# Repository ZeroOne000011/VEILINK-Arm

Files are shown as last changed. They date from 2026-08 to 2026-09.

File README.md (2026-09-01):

# VEILINK 六轴机械臂入门指南

VEILINK 是一款以 3D 打印结构件和飞特 STS3215 总线舵机为基础的六轴机械臂。本仓库整理了制作和调试这款机械臂所需的 3D 模型、装配说明、运动学参数及快速入门程序。

## 关于这个项目

我正在学习机械臂相关知识，VEILINK 是我设计的第一款机械臂，因此在设计和制作过程中，可能仍有一些不够完善的地方。希望这个项目能为同样对机械臂、机器人控制和 3D 打印感兴趣的朋友提供一些灵感，也欢迎大家一起学习、交流和探讨。

项目展示及打印配置可参考：[MakerWorld：VEILINK 六轴机械臂](https://makerworld.com.cn/zh/models/2817152-veilink-liu-zhou-ji-jie-bi#profileId-3285755)。

<p align="center">
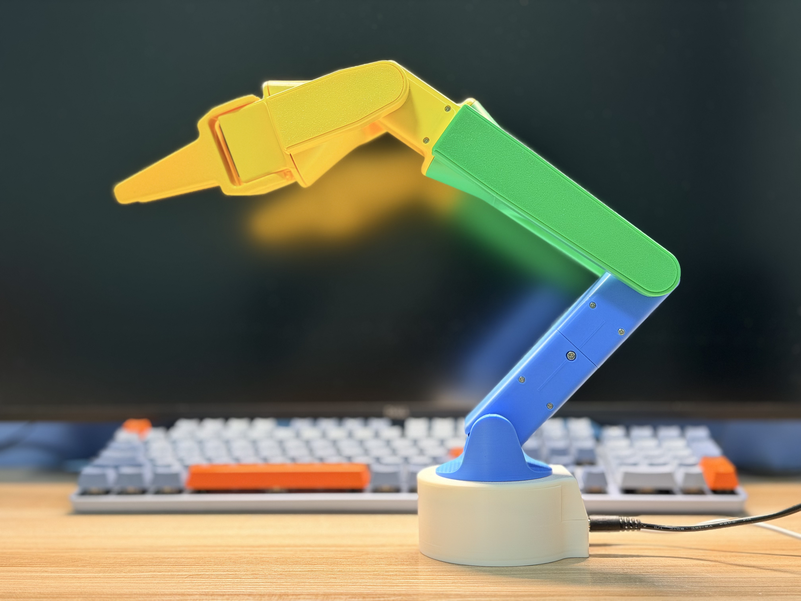
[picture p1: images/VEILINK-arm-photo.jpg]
VEILINK 六轴机械臂实拍图
  
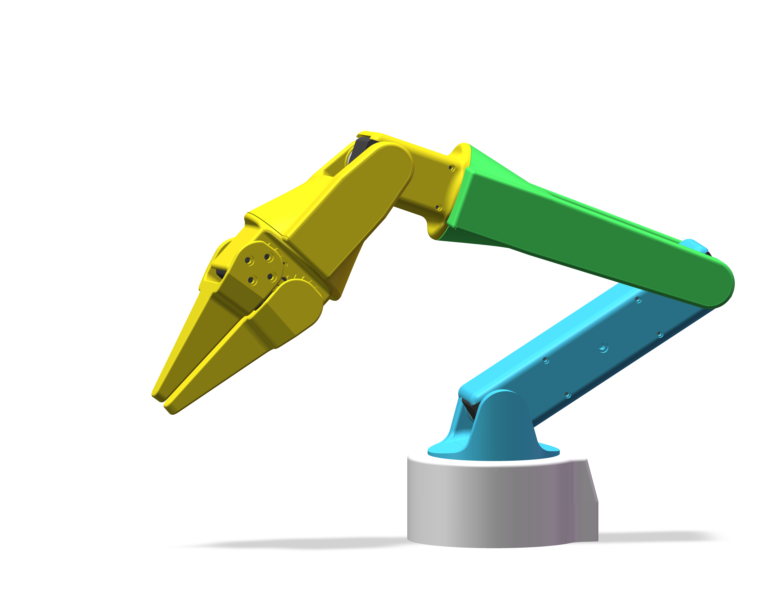
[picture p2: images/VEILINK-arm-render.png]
VEILINK 六轴机械臂 CAD 渲染图
  
</p>

## 仓库内容

| 目录 | 内容 |
| --- | --- |
| [3D Models](<3D Models/>) | 3MF 打印文件、STEP 三维模型和装配说明书 |
| [Code](<Code/>) | 舵机编号、整机校准、单舵机控制和 Xbox 手柄控制 Notebook |
| [运动学参数 Kinematic Parameters](<运动学参数 Kinematic Parameters/>) | 运动学参数说明、DH 参数表、运动学模型和零位示意图 |

主要资料：

- [3D 打印文件](<3D Models/VEILINK Arm 3D Print.3mf>)
- [STEP 三维模型](<3D Models/VEILINK Arm.STEP>)
- [装配说明书](<3D Models/装配说明书 Assembly Instruction.pdf>)
- [DH 参数表](<运动学参数 Kinematic Parameters/DH参数表 DH Parameters.png>)
- [运动学模型](<运动学参数 Kinematic Parameters/运动学模型 Kinematic Model.png>)
- [机械臂零位示意图](<运动学参数 Kinematic Parameters/零位 Zero Pose.PNG>)
- [运动学参数说明](<运动学参数 Kinematic Parameters/运动学参数说明.md>)

## 软件环境

快速入门 Notebook 按 LeRobot 0.5.x API 编写，当前校准记录使用 LeRobot 0.5.1。推荐使用 Anaconda 创建独立的 Python 环境，便于安装依赖、切换环境及避免不同项目之间的版本冲突。

### 1. 安装 Anaconda

前往 [Anaconda 官网](https://www.anaconda.com/download)下载并安装适合当前操作系统的版本。Windows 用户安装完成后，可从开始菜单打开 **Anaconda Prompt** 执行下面的命令。

先确认 Conda 已正确安装：

```powershell
conda --version
```

如果普通 PowerShell 提示找不到 `conda`，可改用 Anaconda Prompt，或在安装完成后重新打开终端。

### 2. 创建并激活项目环境

创建名为 `lerobot`、使用 Python 3.10 的独立环境：

```powershell
conda create -n lerobot python=3.10 -y
conda activate lerobot
```

激活成功后，终端提示符前通常会显示 `(lerobot)`。可以运行以下命令确认当前 Python 来自新环境：

```powershell
python --version
where.exe python
```

### 3. 安装项目依赖

在 `lerobot` 环境中执行：

```powershell
python -m pip install --upgrade pip
python -m pip install "lerobot==0.5.1" pyserial ipykernel ipywidgets jupyter numpy pygame
```

随后将该环境注册为 Jupyter 内核：

```powershell
python -m ipykernel install --user --name lerobot --display-name "Python (lerobot)"
```

### 4. 打开 Notebook

使用 VS Code 或 Jupyter 打开仓库中的 Notebook，并在右上角选择 `Python (lerobot)` 内核。串口号、夹爪选项及其他需要修改的参数，均在对应 Notebook 中标有说明。

以后再次使用时，只需打开 Anaconda Prompt 并激活环境：

```powershell
conda activate lerobot
```

常用的环境管理命令：

```powershell
conda env list                  # 查看已有环境
conda deactivate                # 退出当前环境
conda remove -n lerobot --all   # 删除 lerobot 环境
```

更多用法可参考 [Conda 环境管理文档](https://docs.conda.io/projects/conda/en/latest/user-guide/tasks/manage-environments.html)。

## 推荐使用顺序

### 1. 准备打印件和硬件

使用仓库中的 [3MF 文件](<3D Models/VEILINK Arm 3D Print.3mf>)打印结构件，并根据[装配说明书](<3D Models/装配说明书 Assembly Instruction.pdf>)准备舵机、控制板、电源、紧固件及工具。

### 2. 设置舵机编号

在机械装配前，打开 [1-舵机编号标记.ipynb](<Code/1-舵机编号标记.ipynb>)，按照其中的说明逐台设置舵机 ID、进行通信验证并粘贴实体标签。

### 3. 完成机械装配

按照[装配说明书](<3D Models/装配说明书 Assembly Instruction.pdf>)给出的方向和顺序安装舵机、舵盘、打印件及控制板。装配前后都应核对舵机标签与关节位置。

### 4. 校准零位和安全限位

机械装配完成后，参考[零位示意图](<运动学参数 Kinematic Parameters/零位 Zero Pose.PNG>)，运行 [2-舵机校准.ipynb](<Code/2-舵机校准.ipynb>)，记录各关节零位并采集安全限位。

校准结果会保存到 [机械臂校准参数.json](<Code/机械臂校准参数.json>)。仓库中的参数来自一台实际机械臂，仅用于展示数据结构和提供参考；不同设备的安装误差和安全范围并不相同，请务必为自己的机械臂重新校准。

### 5. 进行单关节调试

校准完成后，运行 [3-单舵机控制.ipynb](<Code/3-单舵机控制.ipynb>)，按照 Notebook 中的安全步骤逐个检查关节的位置反馈、运动方向、零位和限位，再逐步开展后续控制实验。

### 6. 使用 Xbox 手柄控制

完成校准和逐关节验证后，可以运行 [手柄操控机械臂.ipynb](<Code/手柄操控机械臂.ipynb>)，使用 Xbox 手柄控制腕部中心移动、腕部关节、末端旋转和夹爪开合。该 Notebook 使用 Pygame 的 SDL 标准手柄映射，并从同一份校准 JSON 读取 DH 参数、零位和软件限位。

首次使用时，请先完成 Notebook 中的手柄输入预览和离线回归测试，再以最低速度档进行短脉冲实机验证。控制过程中，短按 A 可在控制与保持状态之间切换，长按 A 退出循环并保持位置，B 键用于锁存紧急卸力；软件卸力不能替代实体断电或急停措施。

### 7. 使用运动学资料

需要进行正逆运动学、轨迹规划或上层控制开发时，建议先阅读[运动学参数说明](<运动学参数 Kinematic Parameters/运动学参数说明.md>)，再结合 [DH 参数表](<运动学参数 Kinematic Parameters/DH参数表 DH Parameters.png>)、[运动学模型](<运动学参数 Kinematic Parameters/运动学模型 Kinematic Model.png>)和零位示意图进行验证。

## 安全提示

- 开始装配或调试前，请完整阅读装配说明书和对应 Notebook 中的安全要求。
- 通电前核对舵机额定电压、接线极性、外部电源容量及控制板与电源共地情况。
- 调试承重关节时应可靠固定机械臂并托住连杆，避免卸力后突然下坠。
- 首次运动测试应采用低速、小幅度、逐关节的方式进行。
- 出现异常运动、发热、异味、异响、通信错误或结构干涉时，应立即卸力并切断舵机电源。

```text
准备打印件和硬件
        ↓
设置舵机 ID 并粘贴标签
        ↓
完成机械装配与接线
        ↓
校准零位和安全限位
        ↓
逐关节进行低速、小幅度测试
        ↓
验证 Xbox 手柄输入与安全停止逻辑
        ↓
开展运动学与上层控制开发
```

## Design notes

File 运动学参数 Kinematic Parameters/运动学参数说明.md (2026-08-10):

# VEILINK 六轴机械臂运动学参数说明

本文面向第一次接触机械臂运动学的读者，说明 VEILINK 六轴机械臂的零位、关节方向、标准 DH 参数以及如何用这些参数计算工具中心点（TCP）的位置和姿态。

> 本文中的长度单位均为 **mm**，角度单位均为 **°**。编程计算三角函数前，必须把角度转换为弧度。

## 1. 先认识这台机械臂

VEILINK 机械臂由 6 个旋转关节组成：

- **J1～J3** 主要决定手腕中心在空间中的位置；
- **J4～J6** 主要调整末端执行器的姿态；
- 夹爪开合是独立动作，不计入机械臂的 6 个位姿自由度，也不在本 DH 参数表中。

机械臂的完整“位姿”包含两部分：

- **位置**：TCP 在基座坐标系中的 `x、y、z` 坐标；
- **姿态**：末端坐标系相对于基座坐标系的朝向。

因此，六轴机械臂通常可以同时控制 TCP 的 3 个位置自由度和 3 个姿态自由度。

### 1.1 参考图

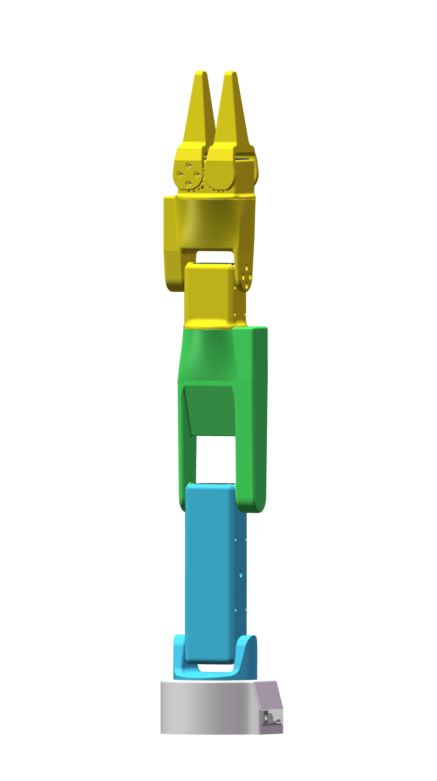
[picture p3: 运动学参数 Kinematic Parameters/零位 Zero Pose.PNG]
VEILINK 机械臂零位实物示意


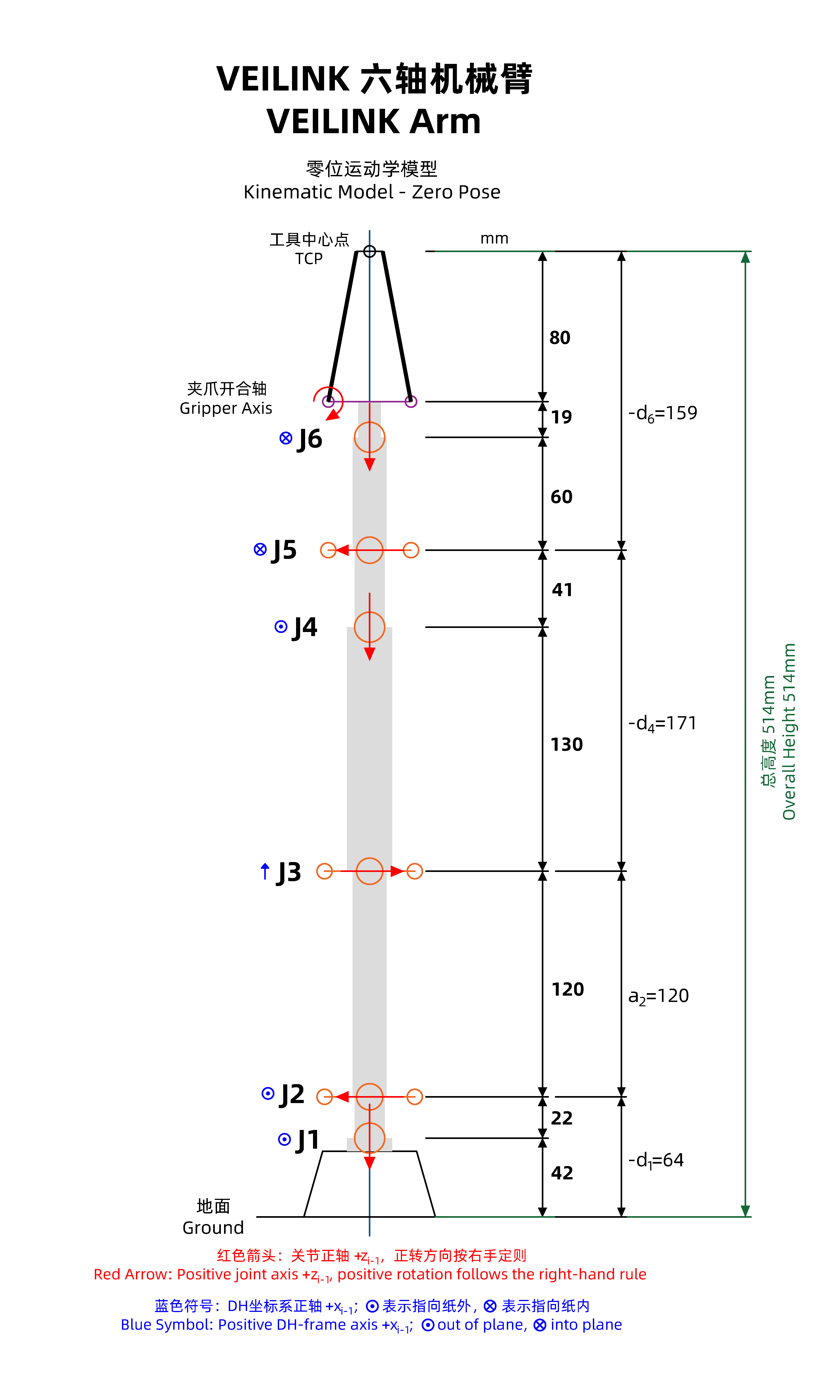
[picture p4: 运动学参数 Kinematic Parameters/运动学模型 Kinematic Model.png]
VEILINK 机械臂零位运动学模型


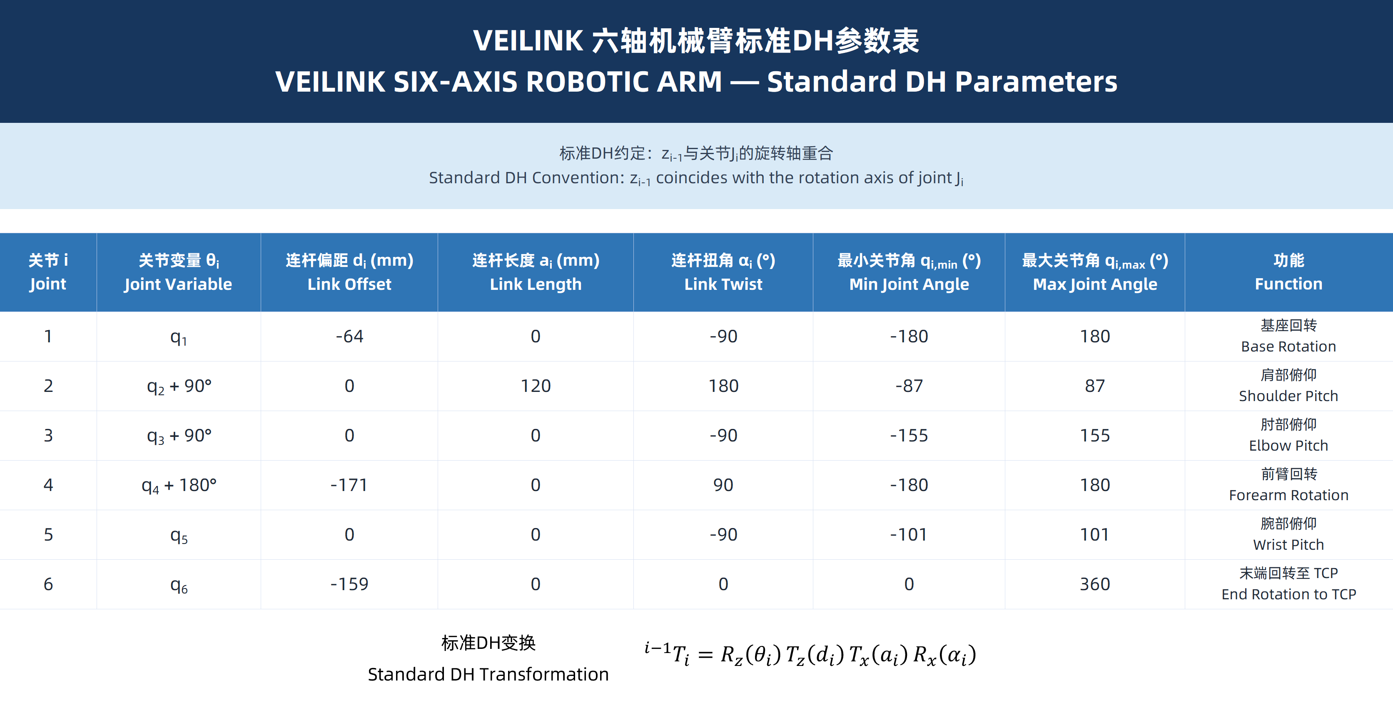
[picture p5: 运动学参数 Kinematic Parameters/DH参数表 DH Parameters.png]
VEILINK 六轴机械臂标准 DH 参数表


## 2. 零位、TCP 与坐标方向

### 2.1 什么是机械零位

本文把下列状态定义为机械臂零位：

```text
q = [q1, q2, q3, q4, q5, q6] = [0°, 0°, 0°, 0°, 0°, 0°]
```

此时机械臂外形如零位图所示，主体连杆大致竖直向上。零位是描述所有关节角的共同参考，不代表舵机原始编码值一定为 0。实际控制时，必须通过校准把舵机编码值换算为本文中的关节角 `qi`。

### 2.2 什么是 TCP

**TCP（Tool Center Point，工具中心点）** 是控制末端工具时使用的参考点。本文模型把 TCP 放在夹爪顶部中心线上。若以后更换夹爪、吸盘或其他工具，应重新测量工具长度，并在第 6 关节之后增加相应的工具变换。

在图示零位中：

- 地面到 TCP 的总高度为 **514 mm**；
- TCP 位于机械臂中心线上；
- 夹爪开合轴位于 TCP 下方 **80 mm**。

### 2.3 图中的箭头和圆点符号

- **红色箭头**：关节正轴 `+z(i-1)`；关节正转遵循右手定则；
- **蓝色符号**：对应 DH 坐标系的正 `+x(i-1)` 方向；
- `⊙`：方向垂直纸面向外；
- `⊗`：方向垂直纸面向内。

右手定则可以这样理解：右手拇指指向关节正轴，其余四指弯曲的方向就是关节角增大的方向。

> 不能只根据屏幕上“顺时针/逆时针”判断正负方向。观察视角改变后，视觉上的旋转方向也会改变；关节正方向应始终由轴向和右手定则确定。

### 2.4 零位图中的主要尺寸

从地面沿竖直方向到 TCP，各段尺寸依次为：

| 区段 | 尺寸（mm） | 说明 |
| --- | ---: | --- |
| 地面到 J1 轴 | 42 | 基座高度的一部分 |
| J1 轴到 J2 轴 | 22 | 与上一段合计得到 `-d1 = 64` |
| J2 轴到 J3 轴 | 120 | 对应 `a2 = 120` |
| J3 轴到 J4 轴 | 130 | 前臂下段尺寸 |
| J4 轴到 J5 轴 | 41 | 与上一段合计得到 `-d4 = 171` |
| J5 轴到 J6 附近参考面 | 60 | 腕部/末端结构尺寸的一部分 |
| 参考面到夹爪开合轴 | 19 | 与相邻尺寸共同构成末端偏距 |
| 夹爪开合轴到 TCP | 80 | 夹爪工具长度 |
| **合计** | **514** | 零位总高度 |

这里出现负的 `d1、d4、d6`，不是长度为负，而是因为相应位移方向与所定义坐标轴正方向相反。

## 3. 标准 DH 参数是什么

DH（Denavit–Hartenberg）方法用 4 个参数描述相邻两节连杆坐标系之间的关系。本文采用的是 **标准 DH（Standard DH）**，约定：

> `z(i-1)` 轴与关节 `Ji` 的旋转轴重合。

每一行 DH 参数包含：

| 参数 | 中文名称 | 对旋转关节的含义 |
| --- | --- | --- |
| `θi` | 关节角 | 绕 `z(i-1)` 旋转的角度；本机械臂的变量项来自 `qi` |
| `di` | 连杆偏距 | 沿 `z(i-1)` 平移的距离 |
| `ai` | 连杆长度 | 沿 `xi` 平移的距离 |
| `αi` | 连杆扭角 | 绕 `xi` 旋转，使 `z(i-1)` 转向 `zi` 的角度 |

对于第 `i` 个关节，从坐标系 `{i-1}` 到 `{i}` 的标准 DH 变换为：

```text
^(i-1)Ti = Rz(θi) · Tz(di) · Tx(ai) · Rx(αi)
```

展开成齐次变换矩阵：

```text
             ┌ cosθ  -sinθ·cosα   sinθ·sinα   a·cosθ ┐
^(i-1)Ti  =  │ sinθ   cosθ·cosα  -cosθ·sinα   a·sinθ │
             │   0       sinα         cosα        d   │
             └   0         0            0         1   ┘
```

矩阵左上角 `3×3` 部分表示姿态，最右侧前三个数表示位置。

> “标准 DH”和“改进 DH（Modified DH）”的坐标系附着方式及变换顺序不同。本文参数不能直接代入改进 DH 公式。

## 4. 本机械臂的 DH 参数

| 关节 | DH 关节变量 `θi` | `di`（mm） | `ai`（mm） | `αi` | `qi` 最小值 | `qi` 最大值 | 主要功能 |
| ---: | --- | ---: | ---: | ---: | ---: | ---: | --- |
| J1 | `q1` | -64 | 0 | -90° | -180° | 180° | 基座回转 |
| J2 | `q2 + 90°` | 0 | 120 | 180° | -87° | 87° | 肩部俯仰 |
| J3 | `q3 + 90°` | 0 | 0 | -90° | -155° | 155° | 肘部俯仰 |
| J4 | `q4 + 180°` | -171 | 0 | 90° | -180° | 180° | 前臂回转 |
| J5 | `q5` | 0 | 0 | -90° | -101° | 101° | 腕部俯仰 |
| J6 | `q6` | -159 | 0 | 0° | 0° | 360° | 末端回转至 TCP |

### 4.1 `qi` 与 `θi` 不完全相同

`qi` 是以机械零位为 0° 的实际关节变量，`θi` 是代入 DH 变换矩阵的角度。两者关系为：

```text
θ1 = q1
θ2 = q2 + 90°
θ3 = q3 + 90°
θ4 = q4 + 180°
θ5 = q5
θ6 = q6
```

`+90°` 或 `+180°` 是由 DH 坐标系定义产生的固定补偿，并不表示机械臂回到零位时还要命令舵机额外旋转这些角度。

### 4.2 为什么只有 `a2` 不为 0

`ai` 表示两根相邻关节轴之间沿公共法线的距离。这个模型中，J2 与 J3 之间存在 **120 mm** 的公共法线距离，因此 `a2=120 mm`；其余相邻轴在各自 DH 建系下相交或共线，所以相应 `ai=0`。

### 4.3 `d4` 和 `d6` 包含哪些实体尺寸

- `-d4=171 mm`，对应图中 `130+41 mm`；
- `-d6=159 mm`，对应图中 `60+19+80 mm`，其终点为 TCP；
- `-d1=64 mm`，对应图中 `42+22 mm`。

这些是用于坐标变换的等效几何尺寸，不要求每个 DH 参数只对应一根独立的实体连杆。

## 5. 六个关节逐一说明

### 5.1 J1：基座回转（Base Rotation）

- **作用**：带动 J2～J6 和末端工具绕基座轴整体旋转，主要改变 TCP 的水平朝向；
- **关节变量**：`θ1=q1`；
- **范围**：`-180° ≤ q1 ≤ 180°`；
- **零位轴向**：正轴沿图中的红色 `+z0`；
- **直观理解**：类似人站在原地转身；
- **注意**：当 TCP 位于基座轴线上时，仅从 TCP 位置可能无法唯一确定 J1，姿态或前一时刻关节角也要参与选解。

### 5.2 J2：肩部俯仰（Shoulder Pitch）

- **作用**：抬起或放下整条手臂，对 TCP 的伸出距离和高度影响很大；
- **关节变量**：`θ2=q2+90°`；
- **范围**：`-87° ≤ q2 ≤ 87°`；
- **几何参数**：`a2=120 mm`；
- **直观理解**：类似人的肩膀带动上臂前后摆动；
- **注意**：接近上下限时应预留减速和机械安全余量，不应把表中理论边界直接当作高速运动边界。

### 5.3 J3：肘部俯仰（Elbow Pitch）

- **作用**：改变手臂弯曲程度，与 J2 配合决定“肘上/肘下”等不同构型；
- **关节变量**：`θ3=q3+90°`；
- **范围**：`-155° ≤ q3 ≤ 155°`；
- **直观理解**：类似人的肘关节屈伸；
- **注意**：同一个 TCP 目标可能有多组 J2/J3 解，逆运动学时要根据限位、避障和与当前姿态的距离选解。

### 5.4 J4：前臂回转（Forearm Rotation）

- **作用**：使腕部绕前臂方向滚转，主要改变末端姿态；
- **关节变量**：`θ4=q4+180°`；
- **范围**：`-180° ≤ q4 ≤ 180°`；
- **几何参数**：`d4=-171 mm`；
- **直观理解**：类似人的前臂旋前/旋后；
- **注意**：固定补偿 `+180°` 只在运动学计算中加入，不能重复加入舵机命令。

### 5.5 J5：腕部俯仰（Wrist Pitch）

- **作用**：使末端工具抬头或低头，是调整夹爪朝向的关键关节；
- **关节变量**：`θ5=q5`；
- **范围**：`-101° ≤ q5 ≤ 101°`；
- **直观理解**：类似手腕上下弯曲；
- **注意**：在 `q5` 接近某些轴线重合构型（特别是零附近）时，J4 与 J6 对姿态的作用可能耦合，属于腕部奇异附近，应避免用很大的关节速度追踪微小姿态变化。

### 5.6 J6：末端回转（End Rotation）

- **作用**：使夹爪绕末端中心轴旋转；
- **关节变量**：`θ6=q6`；
- **范围**：`0° ≤ q6 ≤ 360°`；
- **几何参数**：`d6=-159 mm`，从腕部坐标系延伸到 TCP；
- **直观理解**：类似拧动螺丝刀；
- **注意**：0° 与 360° 的几何姿态相同，但控制器数值可能不同。轨迹规划应采用连续角度或最短角差，避免在边界处突然反转一整圈。

### 5.7 夹爪开合轴（Gripper Axis）

夹爪开合只改变两指间距，不改变本文定义的 TCP 坐标系，因此没有单独的 DH 行。若抓取物体后希望把抓取点而不是夹爪顶部中心作为 TCP，应增加一个工具坐标系，并写出从当前 TCP 到新工具点的固定变换。

## 6. 如何计算正运动学

正运动学解决的问题是：**已知六个关节角，求 TCP 的位置和姿态。**

计算步骤：

1. 输入机械零位定义下的 `q1～q6`；
2. 检查每个 `qi` 是否在关节范围内；
3. 按上文关系计算 `θ1～θ6`；
4. 将每行的 `θi、di、ai、αi` 代入标准 DH 矩阵，得到 `^(i-1)Ti`；
5. 按关节顺序左乘：

```text
^0T6 = ^0T1 · ^1T2 · ^2T3 · ^3T4 · ^4T5 · ^5T6
```

最终矩阵写作：

```text
       ┌ r11 r12 r13 px ┐
^0T6 = │ r21 r22 r23 py │
       │ r31 r32 r33 pz │
       └  0   0   0   1 │
```

- `p=[px,py,pz]ᵀ` 是 TCP 在基座坐标系中的位置；
- `R`（左上角 `3×3`）是 TCP 的姿态旋转矩阵。

### 6.1 可直接参考的 Python 实现

```python
import numpy as np

def dh_standard(theta_deg, d_mm, a_mm, alpha_deg):
    """返回标准 DH 齐次变换矩阵。"""
    theta = np.deg2rad(theta_deg)
    alpha = np.deg2rad(alpha_deg)
    ct, st = np.cos(theta), np.sin(theta)
    ca, sa = np.cos(alpha), np.sin(alpha)

    return np.array([
        [ct, -st * ca,  st * sa, a_mm * ct],
        [st,  ct * ca, -ct * sa, a_mm * st],
        [0.0,      sa,       ca,       d_mm],
        [0.0,     0.0,      0.0,        1.0],
    ])

def forward_kinematics(q_deg):
    """q_deg: [q1, q2, q3, q4, q5, q6]，单位为度。"""
    q = np.asarray(q_deg, dtype=float)
    if q.shape != (6,):
        raise ValueError("q_deg 必须包含 6 个关节角")

    q_min = np.array([-180, -87, -155, -180, -101,   0], dtype=float)
    q_max = np.array([ 180,  87,  155,  180,  101, 360], dtype=float)
    if np.any(q < q_min) or np.any(q > q_max):
        raise ValueError("存在超出 DH 参数表范围的关节角")

    theta = q + np.array([0, 90, 90, 180, 0, 0], dtype=float)
    d = np.array([-64, 0, 0, -171, 0, -159], dtype=float)
    a = np.array([0, 120, 0, 0, 0, 0], dtype=float)
    alpha = np.array([-90, 180, -90, 90, -90, 0], dtype=float)

    T = np.eye(4)
    for values in zip(theta, d, a, alpha):
        T = T @ dh_standard(*values)
    return T

T_0_tcp = forward_kinematics([0, 0, 0, 0, 0, 0])
print(T_0_tcp)
print("TCP position (mm):", T_0_tcp[:3, 3])
```

### 6.2 用零位做自检

将 `q=[0,0,0,0,0,0]°` 代入本文参数，理论结果为：

```text
         ┌ -1  0  0    0 ┐
^0Ttcp = │  0 -1  0    0 │
         │  0  0  1 -514 │
         └  0  0  0    1 ┘
```

这表示：

- TCP 位于基座中心线上；
- 沿本模型定义的基座 `+z0` 反方向移动 514 mm；
- 物理上对应图中的“从地面竖直向上 514 mm”；
- TCP 坐标系的 x、y 轴相对基座各反向，z 轴同向。

如果零位计算结果不是这个位置，优先检查：是否误用了改进 DH、矩阵相乘顺序是否颠倒、是否遗漏固定角补偿，以及角度是否正确转换为弧度。

## 7. 逆运动学、限位与奇异位形

逆运动学解决的问题是：**已知期望 TCP 位姿，求六个关节角。** 它通常比正运动学更复杂，原因包括：

- 同一目标位姿可能有多组关节解；
- 某些目标超出机械臂工作空间，没有可行解；
- 数学上存在的解可能超过关节限位或发生结构干涉；
- 奇异位形附近，末端的小变化可能需要很大的关节运动。

常见选解原则：

1. 先剔除超过各关节范围的解；
2. 再剔除会造成连杆、夹爪、桌面或环境碰撞的解；
3. 优先选择与当前关节角距离较小的连续解；
4. 给机械限位和奇异位形留出安全余量；
5. 在真实机械臂上先低速、单步、小幅度验证。

需要特别留意的构型包括：手臂接近完全伸直或折叠，以及腕部轴线接近重合。此时机械臂仍可能处在正常几何位置，但某些方向的运动能力下降，数值逆解也可能变得不稳定。

## 8. 从运动学角度到真实舵机指令

DH 模型中的 `qi` 与舵机内部位置值之间通常还隔着一层标定关系：

```text
舵机编码值 → 零位偏置修正 → 方向符号修正 → 关节角 qi → DH 角 θi
```

实际使用时应分别保存：

- 每个关节的舵机编号；
- 机械零位对应的编码值；
- 编码增大是否等于本文关节正方向；
- 实机测得的安全软限位；
- 编码值与角度之间的比例关系。

> DH 参数表中的角度范围用于运动学建模和规划参考，不能替代具体机械臂的实机校准、碰撞检查和安全软限位。

## 9. 初学者常见问题

### 为什么 `d` 可以是负数？

`d` 是带方向的坐标位移，不是物体的“负长度”。负号只表示位移方向与相应 z 轴正方向相反。

### 为什么零位时 `θ2、θ3、θ4` 不是 0°？

因为 `θi` 是 DH 坐标系之间的角度，而 `qi` 是以机械零位为基准的关节角。固定的 90° 或 180° 用于把两套定义对齐。

### 为什么 J6 的范围写成 0°～360°？

它表达一整圈可用范围。0° 与 360° 姿态等价，但规划连续轨迹时仍要处理数值跨界问题，并核对线缆是否允许连续回转。

### 只控制 TCP 位置，是否一定要用六个关节？

不一定。前三个关节通常承担主要定位任务，后三个关节主要负责姿态，但各关节并非完全独立。完整的空间位姿控制仍需联合求解六个关节。

### 更换夹爪后要重新做整套 DH 参数吗？

如果 J1～J6 的结构没有变化，通常不必修改前六行 DH 参数，只需重新定义从 J6 到新 TCP 的工具变换；若第 6 轴到安装面的结构尺寸也改变，则应同步更新相应末端偏距。

## 10. 建议的学习与验证顺序

1. 对照零位实物图识别 J1～J6 和夹爪轴；
2. 用右手定则逐个确认关节正方向；
3. 理解 `qi`、`θi` 与固定角补偿的区别；
4. 用零位验证正运动学结果和 514 mm 总高度；
5. 给单个关节增加少量角度，观察 TCP 位置和姿态的变化；
6. 加入关节限位、连续角度处理和碰撞检查；
7. 最后再学习数值逆运动学、雅可比矩阵和轨迹规划。

完成以上步骤后，就具备了使用本组参数进行正运动学验证、逆运动学开发和上层轨迹规划的基础。

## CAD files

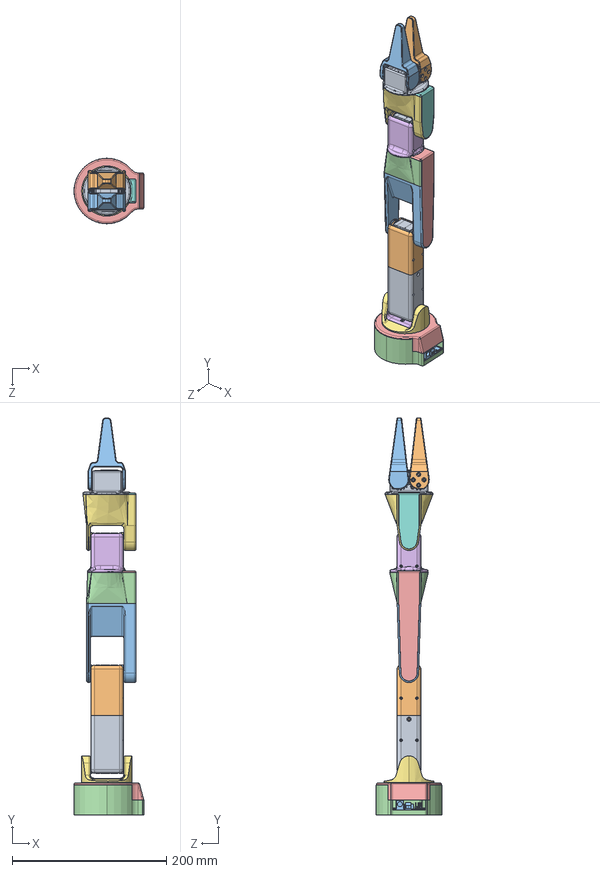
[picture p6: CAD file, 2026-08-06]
3D Models/VEILINK Arm.STEP
90.7 x 514.0 x 85.0 mm
ST3215电机 x 7
舵盘 x 7
驱动板
底座
底座盖
肩部旋转
肩部旋转盖
辅助舵盘 x 4
上臂
前臂
前臂腕部底座
前臂装饰盖
腕部俯仰底座
末端旋转底座
腕部装饰盖
夹爪固定底座
夹爪
辅助夹爪

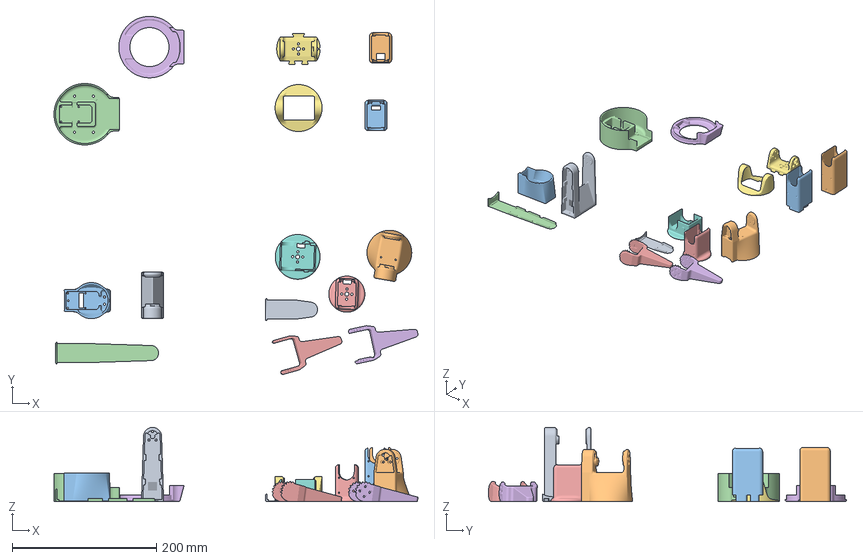
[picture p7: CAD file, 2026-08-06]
3D Models/VEILINK Arm 3D Print.3mf
503.9 x 495.9 x 102.6 mm
前臂.STEP
末端旋转底座.STEP
前臂腕部底座.STEP
前臂装饰盖.STEP
腕部俯仰底座.STEP
夹爪.STEP
肩部旋转盖.STEP
夹爪固定底座.STEP
腕部装饰盖.STEP
上臂_1
上臂_2
底座.STEP
辅助夹爪.STEP
底座盖.STEP
肩部旋转.STEP

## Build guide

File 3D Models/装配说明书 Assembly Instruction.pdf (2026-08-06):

# VEILINK 六轴机械臂

# VEILINK Six-Axis Robotic Arm

# 装配说明书

# Assembly Instruction

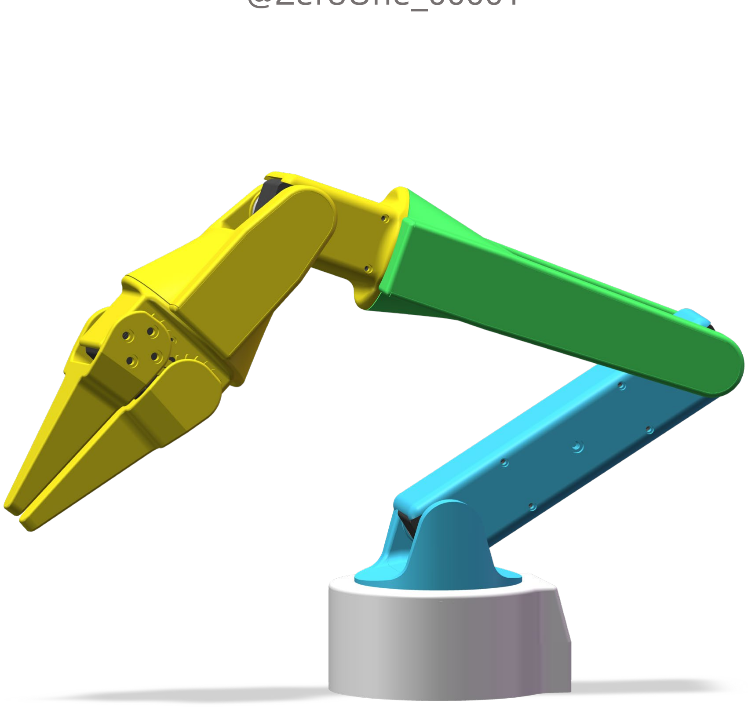
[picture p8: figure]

### @ZeroOne_00001

# 材料清单

## BOM

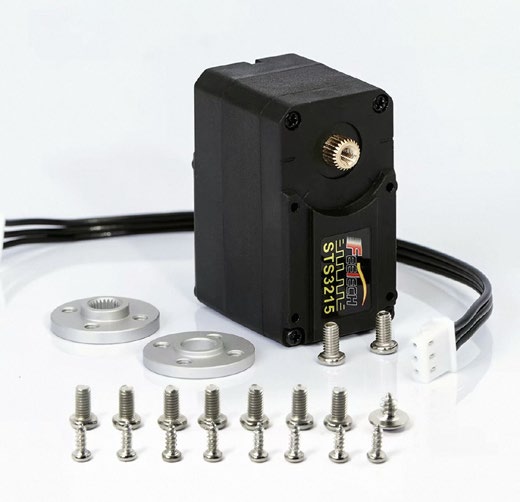
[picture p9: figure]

飞特舵机STS3215 C001 7.4V
FEETECH STS3215 C001 7.4V

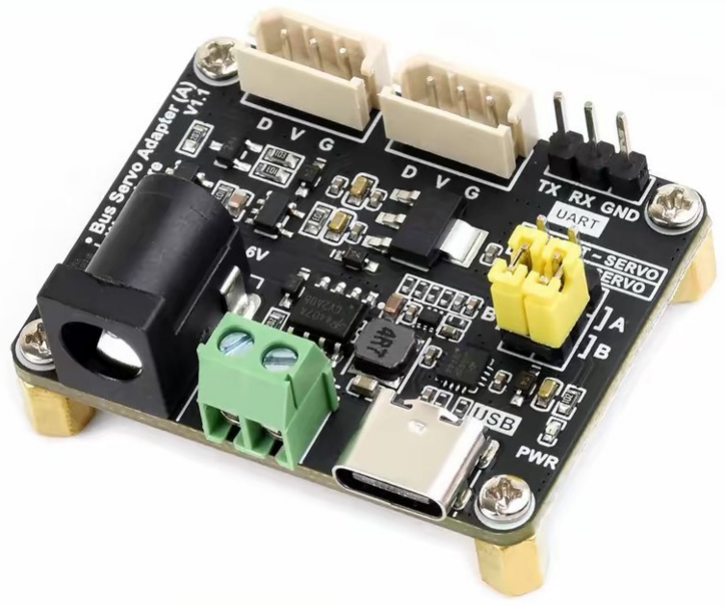
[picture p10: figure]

微雪总线舵机驱动板
WAVESHARE Bus Servo Adapter

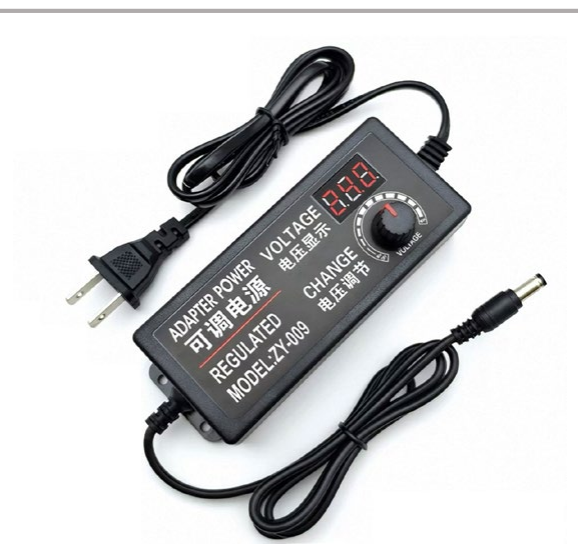
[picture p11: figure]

3-12V可调电源
3–12 V Adjustable Power Supply

3D打印件
3D-Printed Parts

Type-c USB数据线
USB Type-C Data Cable

https://e.tb.cn/h.8gToyH7nGQLqJIb?tk=YCCKgyzv9Hm (https://e.tb.cn/h.8gToyH7nGQLqJIb?tk=YCCKgyzv9Hm)

https://e.tb.cn/h.8gTOINQEOKyP67f?tk=t9xmgyzsh4T (https://e.tb.cn/h.8gTOINQEOKyP67f?tk=t9xmgyzsh4T)

https://e.tb.cn/h.8TIiKoLDCdxslsV?tk=bbOtgyAhpHh (https://e.tb.cn/h.8TIiKoLDCdxslsV?tk=bbOtgyAhpHh)

×7

×1

×1

×1

×15

# 装配前须知

### 欢迎制作 VEILINK 六轴机械臂！为确保装配过程顺利， 请在开始前阅读以下内容。

## 快速入门与代码

### 快速入门指南、运动学参数及相关资料：

https://github.com/ZeroOne000011/VEILINK-Arm

## 注意事项

### - 由于舵机外观相同，请务必在装配前完成舵机ID设 置，并在安装前再次核对每个舵机的编号和安装位 置。编号错误可能导致关节动作异常、运动方向不 正确，甚至造成机械结构碰撞。 - 建议按照说明书中的方向安装舵机和摆臂。 - 在打印件完全冷却后再拆除支撑，并清理毛边及孔 内残留材料。必要时可先试装螺丝，确认各连接位 置配合正常。预计装配时间约为20分钟。

## 建议准备的工具

### - 十字螺丝刀 - 尖嘴钳

- 剪钳

## Before Assembly

Welcome to the VEILINK Six-Axis Robotic Arm project! To ensure a smooth assembly process, please read the following information before getting started.

## Quick Start Guide and Code

Quick-start guide, kinematic parameters, and related opensource resources:
https://github.com/ZeroOne000011/VEILINK-Arm

## Important Notes

- Since all the servos look identical, make sure to configure their IDs before assembly. Before installation, doublecheck each servo ID and its corresponding mounting position. An incorrect ID may cause abnormal joint movement, an incorrect direction of rotation, or even collisions between mechanical parts.
- Install the servos and servo horns in the orientations shown in the assembly guide.
- Allow the printed parts to cool completely before removing the supports. Clean away any rough edges and residual material inside the holes. If necessary, test-fit the screws first to ensure that all parts fit together correctly.The estimated assembly time is approximately 20 minutes.

## Recommended Tools

- Phillips screwdriver
- Needle-nose pliers
- Flush cutters

1

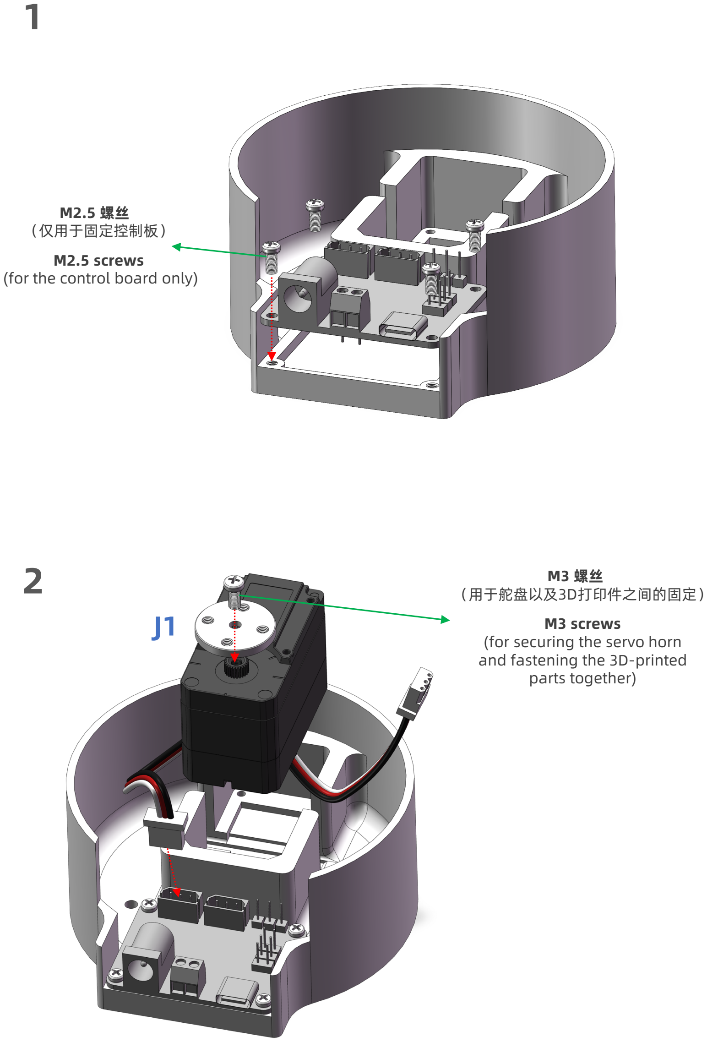
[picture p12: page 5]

2

M2.5 螺丝
（仅用于固定控制板）
M2.5 screws
(for the control board only)

M3 螺丝
（用于舵盘以及3D打印件之间的固定）
M3 screws
(for securing the servo horn and fastening the 3D-printed parts together)

J1

3

4

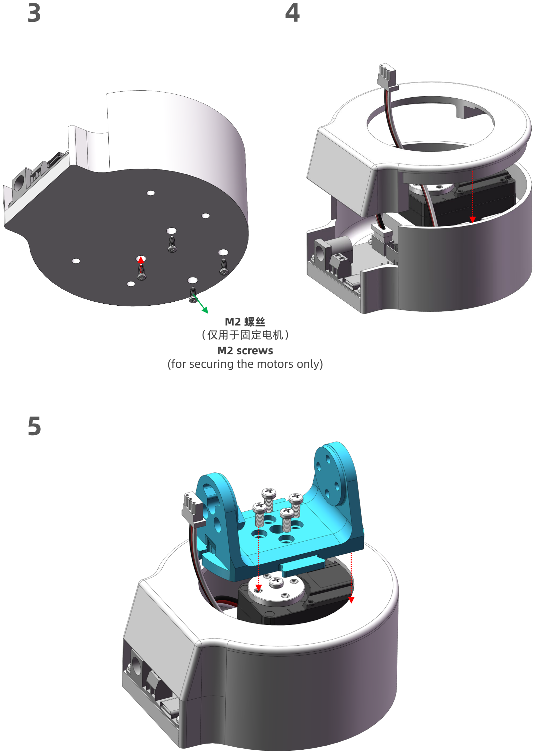
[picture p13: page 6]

5

M2 螺丝
（仅用于固定电机）
M2 screws
(for securing the motors only)

6

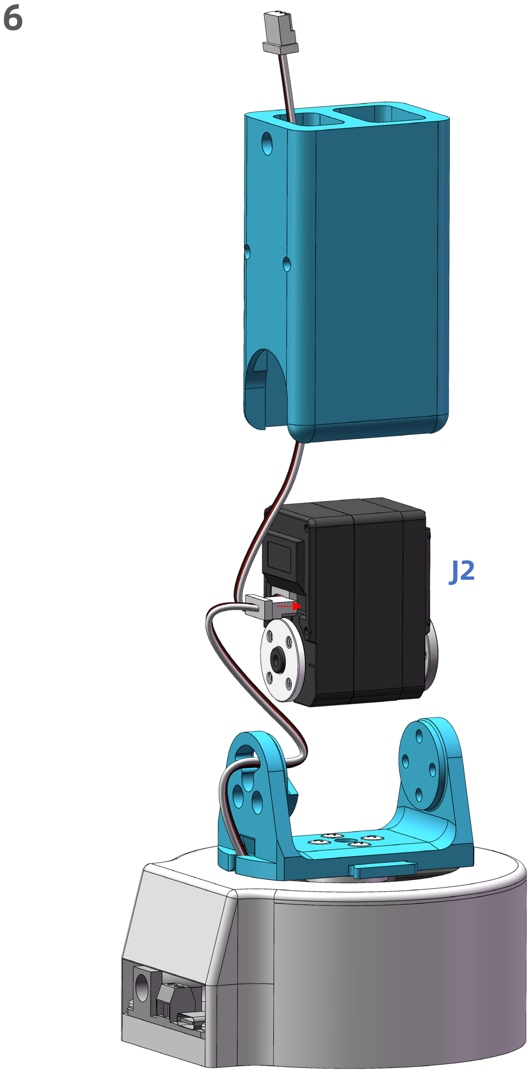
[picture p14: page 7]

J2

7

8

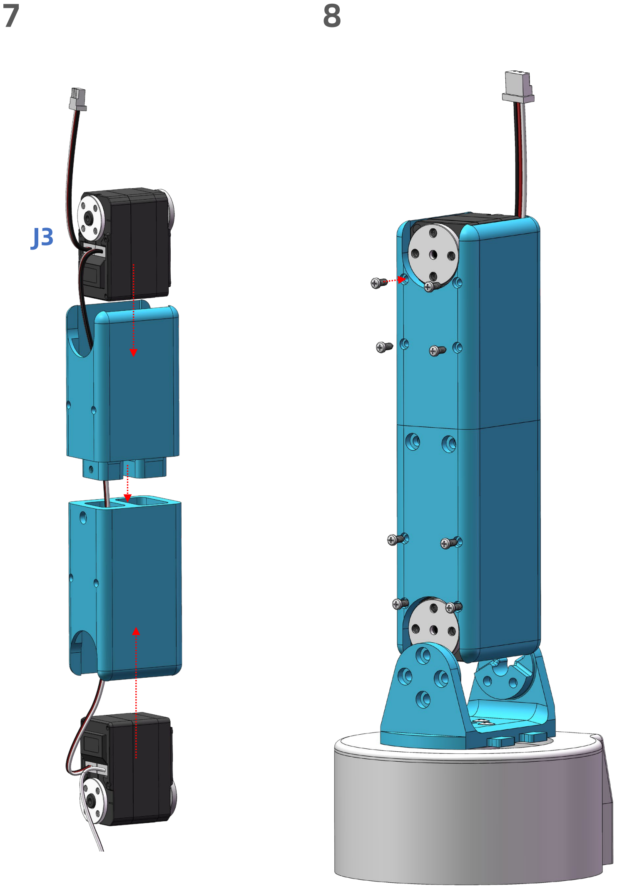
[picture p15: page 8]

J3

9 10

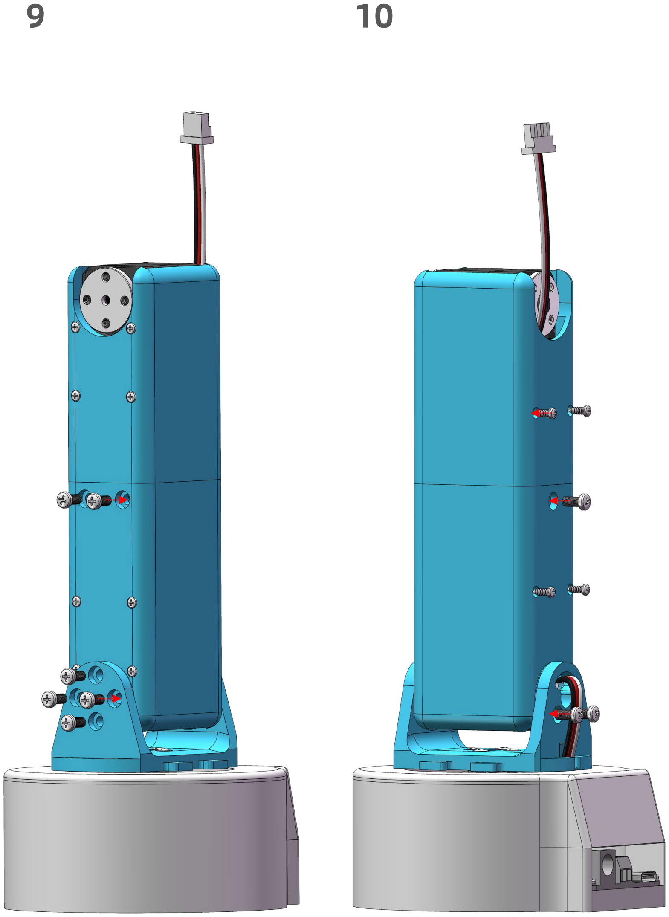
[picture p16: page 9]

11 12

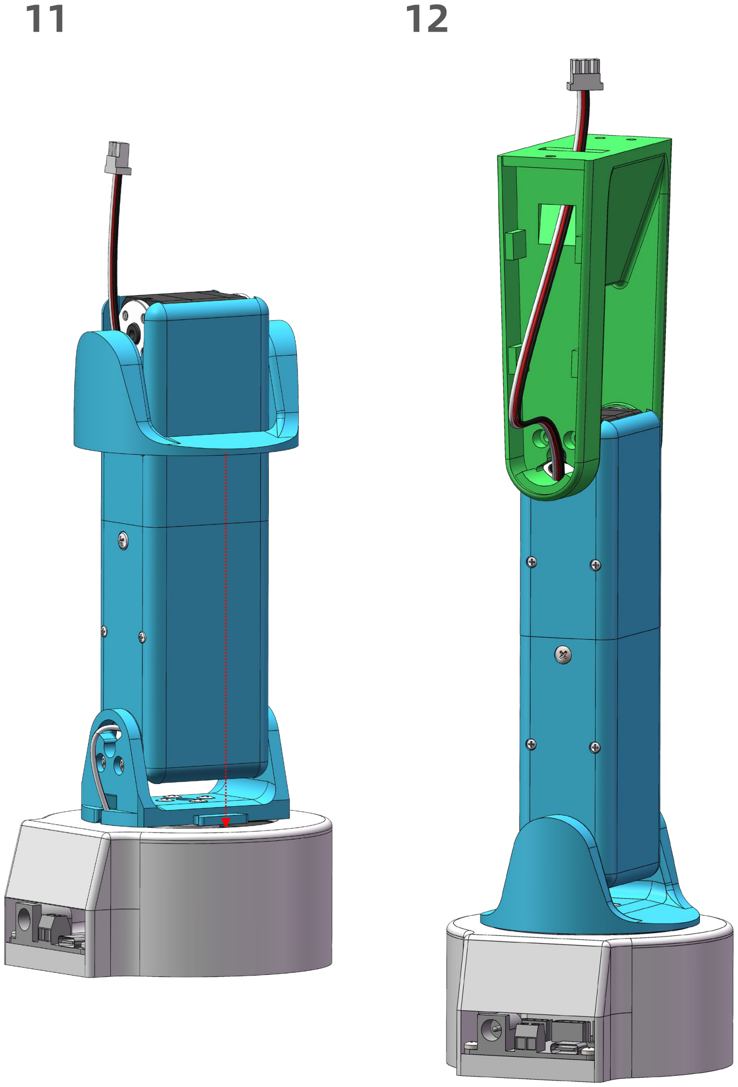
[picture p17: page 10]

13 14

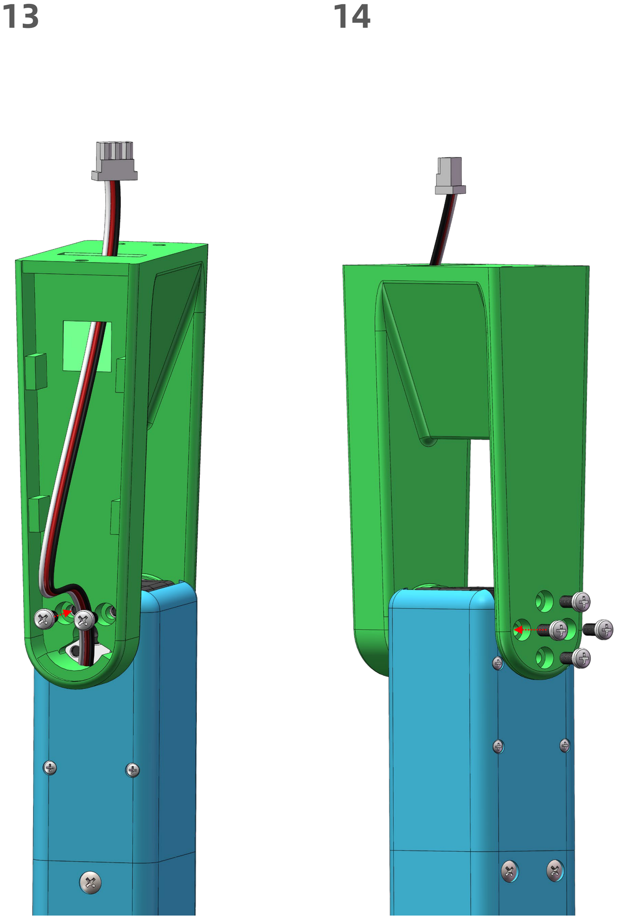
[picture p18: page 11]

15 16

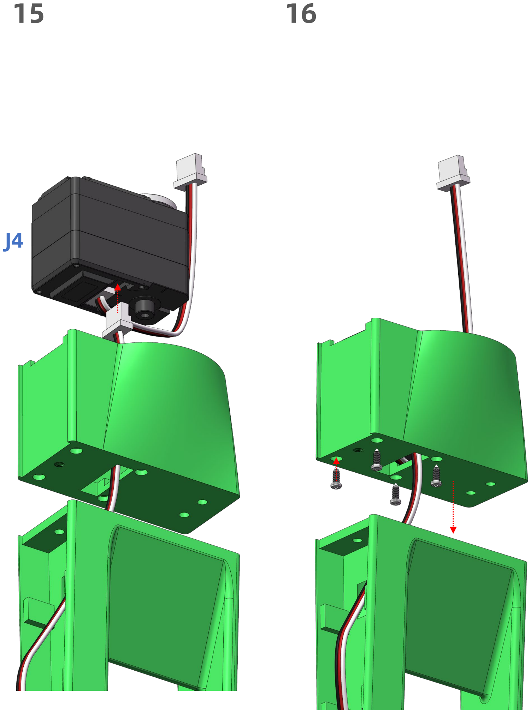
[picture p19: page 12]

J4

17 18

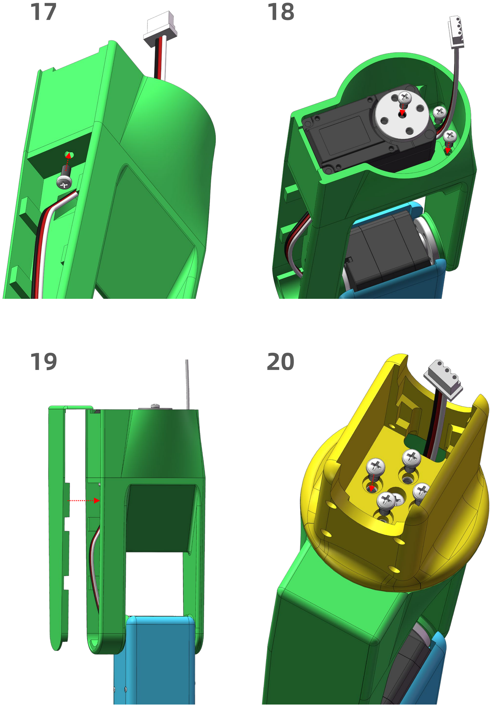
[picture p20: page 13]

19 20

21 22

J5

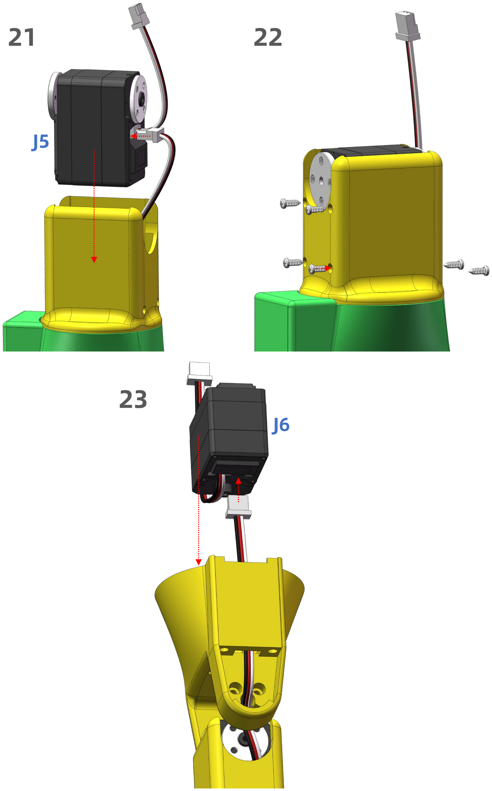
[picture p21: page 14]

23
J6

24 25

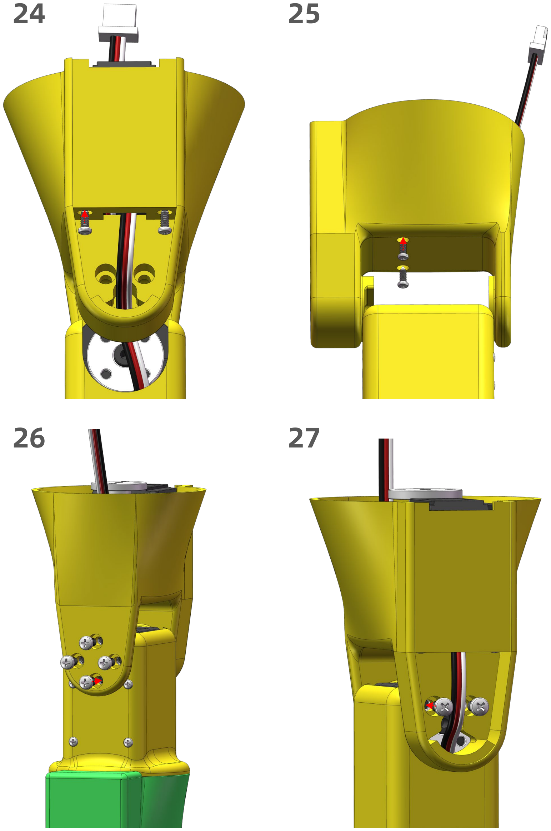
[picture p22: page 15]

26 27

28 29

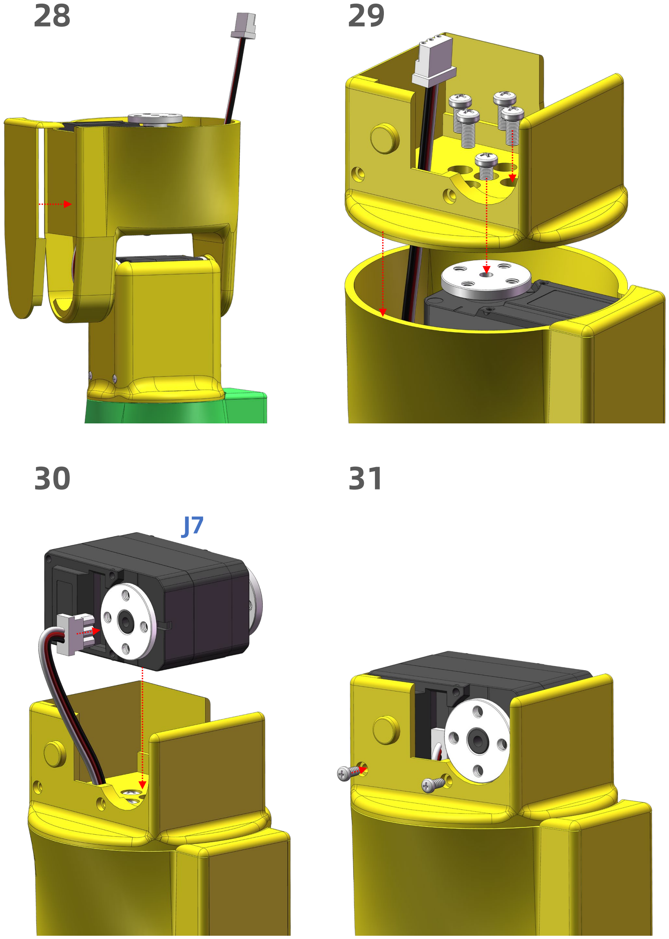
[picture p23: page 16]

30 31
J7

32 33

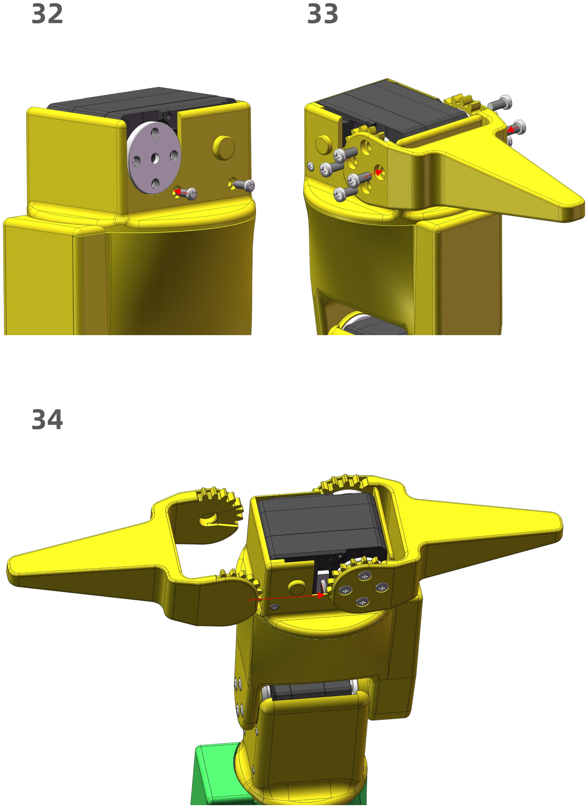
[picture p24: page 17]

34

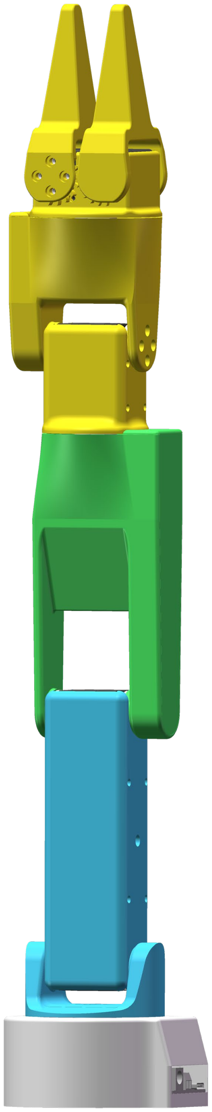
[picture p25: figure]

35

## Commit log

2026-08-06 发布 VEILINK 入门资料
    [DH参数表 DH Parameters.xlsx, VEILINK Arm 3D Print.3mf, VEILINK Arm.STEP]
2026-08-06 精简 README 项目指南
2026-08-07 补充 Anaconda 环境教程
2026-08-07 添加运动学参数
    [DH参数表 DH Parameters.xlsx]
2026-08-09 修改README
